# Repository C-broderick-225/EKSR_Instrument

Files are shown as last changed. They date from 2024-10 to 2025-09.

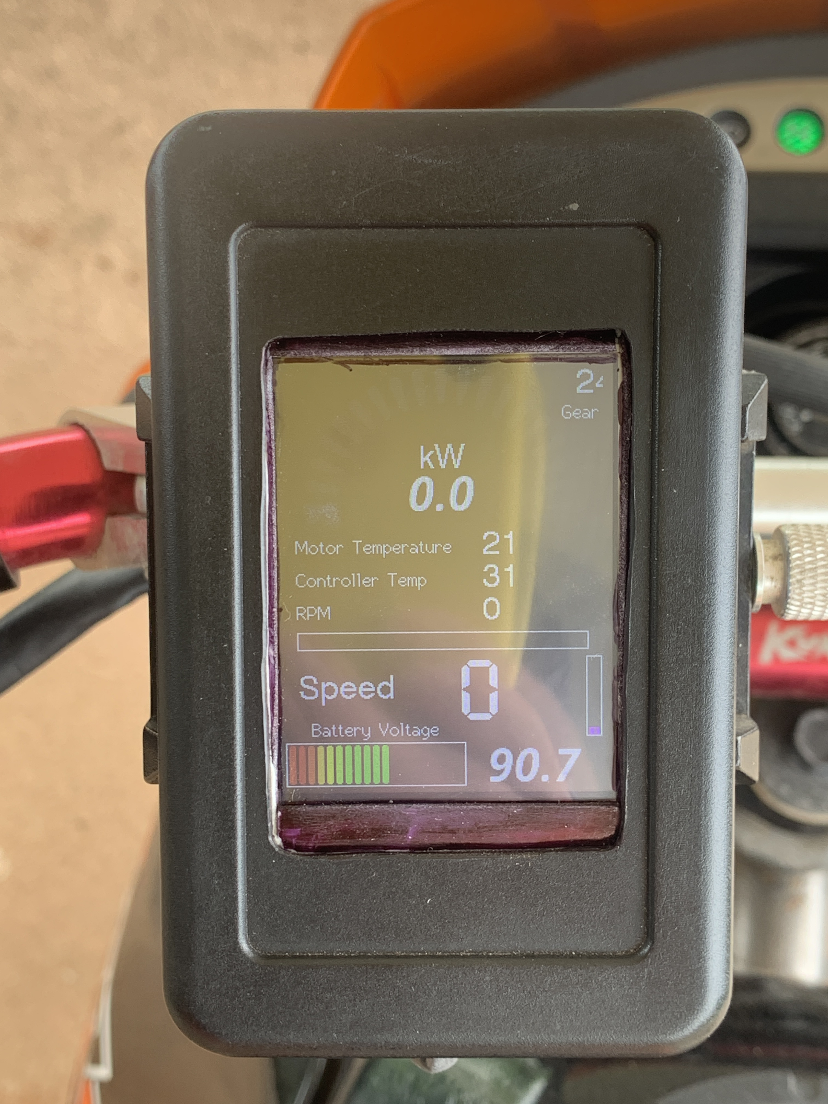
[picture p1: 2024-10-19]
media/EKSR_display.jpg

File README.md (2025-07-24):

# EKSR_Instrument (Fork)

**This repository is a fork of the original [EKSR_Instrument](https://github.com/magicmicros/EKSR_Instrument) project.**

## Overview
This project serves as the foundation for a new product based on the EKSR_Instrument hardware and firmware. It utilizes an ESP32-S3 microcontroller to receive and decode messages from FarDriver motor controllers over BLE, and displays the processed data on a 2.4" TFT touchscreen display.

## ESP32-S3 BLE Multi-Role Support
The ESP32-S3 (including the ESP32-S3-WROOM-1 module) is capable of acting as both a BLE client (central) and a BLE server (peripheral) simultaneously. This allows the device to connect to a BLE peripheral (such as a Far Driver controller) while also advertising its own BLE service for other clients (such as an Android phone) to connect and receive forwarded data. This multi-role (dual-role) capability is officially supported by Espressif and is useful for BLE proxy/bridge applications.

**Key facts:**
- The ESP32-S3 can operate as both a BLE client and server at the same time (multi-role topology).
- This is supported by the ESP-IDF and ESP-NimBLE host stack.
- Example use case: ESP32-S3 connects to a Far Driver controller as a client, and simultaneously acts as a server to forward data to a mobile app.

**Official documentation:**
- [ESP-IDF BLE Introduction: Bluetooth LE Network Topology](https://docs.espressif.com/projects/esp-idf/en/stable/esp32s3/api-guides/ble/get-started/ble-introduction.html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)
- [ESP-NimBLE API Reference](https://docs.espressif.com/projects/esp-idf/en/stable/esp32s3/api-reference/bluetooth/esp-nimble/index.html)

## Purpose
The goal of this fork is to extend and adapt the original EKSR_Instrument platform for new applications and features. All original design and implementation credit belongs to the original author. This repository will introduce new features, modifications, and documentation specific to the goals of the new product.

## FarDriver BLE Emulator
A FarDriver BLE emulator is included in the `emulator/` directory. This tool allows you to use an ESP32 (such as ESP-WROVER-E) as a BLE peripheral that mimics the FarDriver controller. It is useful for testing the EKSR Instrument firmware without requiring the actual controller hardware.

- The emulator advertises the same BLE service and characteristic UUIDs as the real controller.
- It sends realistic, cyclic data packets for rpm, voltage, temperature, throttle, and more.
- The EKSR Instrument client can connect and display the emulated data as if it were connected to a real FarDriver controller.

For build instructions, customization, and protocol details, see [`emulator/README.md`](emulator/README.md).

## License
See the LICENSE file for details.

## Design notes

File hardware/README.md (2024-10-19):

# Hardware for the EKSR Instrument.

The circuit is pretty straightforward.

The 12V input is dropped to 3.3V by an Alpha & Omega AOZ1284PI buck converter.

The ESP32-S3 controls the ILI9341 based TFT display though SPI and get touch data from the resistive touchcreen, using 4 ADC inputs.

The backlight is controlled with PWM through a N-channel FET.

Rev B adds a input voltage monitor though a 16:1 resistor divider, giving 900mV at 14.4V in.

Programming and log data output is, as usual for the ESP32's, through a 3.3V TTL level serial port.

Communication with the controller is though the built-in BLE in the ESP32-S3 (using Nimble BLE stack).

The board fits into a SZOMK AK-H-15 enclosure.\
This is not the enclosure used for the prototype, but it's the same inner dimensions and have an improved water seal.\
Still, the display have to be sealed against the enclosure, perhaps using a cutout "gasket" from 0.5mm rubber or silicone.

The `.brd` and `.sch` files in the `Fusion Files` folder, is EAGLE V9.x format.\
Project is originally made with Fusion 360/Fusion Electronics.

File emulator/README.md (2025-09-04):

# EKSR Instrument Emulator Suite

This directory contains a comprehensive suite of emulators and testing tools for the EKSR Instrument project. These tools allow you to test and develop the EKSR Instrument firmware without requiring the actual hardware components.

## Overview

The emulator suite includes:
- **FarDriver BLE Emulators** - Simulate the FarDriver controller's BLE communication
- **Hall Motor Emulator** - Simulate BLDC motor Hall sensor signals
- **Testing Tools** - Python scripts for validating emulator behavior and packet formats

## Components

### 1. FarDriver BLE Emulator

#### FarDriverEmulator (Enhanced)
- **Location**: `FarDriverEmulator/FarDriverEmulator.ino`
- **Features**: Enhanced FarDriver BLE protocol emulation with CRC-16/MODBUS checksums and dynamic ebike simulation
- **Use Case**: Accurate protocol emulation with proper error checking and realistic simulation

**Key Features**:
- CRC-16/MODBUS checksums for robust error detection
- Enhanced packet validation and error handling
- Improved timing and connection management
- Realistic ebike simulation with dynamic acceleration/deceleration patterns

### 2. Hall Motor Emulator

#### HallMotorEmulator
- **Location**: `MotorEmulator/HallMotorEmulator/HallMotorEmulator.ino`
- **Purpose**: Simulates BLDC motor Hall sensor signals for motor controller testing
- **Use Case**: Bench testing motor controllers without physical motors

**Features**:
- Generates standard 6-step commutation sequence
- Prevents "Hall Sensor Fault" errors during testing
- Configurable simulated motor speed
- Real-time debug output

### 3. Testing Tools

#### test_emulator_rpm.py
- **Purpose**: Validates RPM calculation logic between emulator and firmware
- **Tests**: Speed-to-RPM conversion accuracy and packet generation
- **Use Case**: Debugging speed display issues

#### test_packet_format.py
- **Purpose**: Validates packet format compliance with FarDriver protocol
- **Tests**: Packet structure, checksums, and data parsing
- **Use Case**: Ensuring emulator generates correct packet formats

#### test_speed_calculation.py
- **Purpose**: Tests speed calculation logic and identifies display issues
- **Tests**: Speed-to-RPM conversion and firmware parsing
- **Use Case**: Debugging speed calculation problems

## Quick Start Guide

### Setting Up FarDriver BLE Emulator

1. **Hardware Requirements**:
   - ESP32 development board (e.g., ESP-WROVER-E)
   - USB cable for programming and power

2. **Software Setup**:
   ```bash
   # Install Arduino IDE with ESP32 support
   # Install NimBLE-Arduino library
   ```

3. **Flashing**:
   - Open `FarDriverEmulator/FarDriverEmulator.ino` in Arduino IDE
   - Select your ESP32 board
   - Upload the sketch
   - Open Serial Monitor at 115200 baud

### Setting Up Hall Motor Emulator

1. **Hardware Requirements**:
   - ESP32 development board
   - Multimeter for pin identification
   - Jumper wires

2. **Wiring** (see MotorEmulator/README.md for detailed instructions):
   ```
   ESP32 Pin | Controller Hall Connector
   GND       | Ground
   GPIO 25   | Hall A Signal
   GPIO 26   | Hall B Signal
   GPIO 27   | Hall C Signal
   ```

3. **Flashing**:
   - Open `MotorEmulator/HallMotorEmulator/HallMotorEmulator.ino`
   - Upload to ESP32
   - Power on motor controller

### Running Tests

```bash
# Test RPM calculations
python test_emulator_rpm.py

# Test packet formats
python test_packet_format.py

# Test speed calculations
python test_speed_calculation.py
```

## FarDriver BLE Protocol Details

### Service Configuration
- **FarDriver Service**: UUID `FFE0`, Characteristic `FFEC`
- **Nordic UART Service**: Standard NUS implementation
- **Device Name**: `FarDriver_Emu`

### Packet Format
- **Size**: 16 bytes
- **Header**: `0xAA`
- **Indices**: 0, 1, 4, 13 (cycled every 30ms)
- **Checksum**: XOR (v1) or CRC-16/MODBUS (v2)

### Packet Types
- **Index 0**: Main data (RPM, gear, current iq/id)
- **Index 1**: Battery voltage
- **Index 4**: Controller temperature
- **Index 13**: Motor temperature and throttle position

### Ebike Simulation
The emulators provide realistic ebike simulation with:
- **30-second cycles**: Acceleration → Maintain → Deceleration
- **Dynamic data relationships**: All parameters calculated from speed
- **Realistic physics**: Proper gear ratios and wheel circumference
- **Visual feedback**: LED status indication

## Hall Motor Emulation Details

### 6-Step Commutation Sequence
```
Step | Hall A | Hall B | Hall C
-----|--------|--------|--------
1    | 1      | 0      | 1
2    | 0      | 0      | 1
3    | 0      | 1      | 1
4    | 0      | 1      | 0
5    | 1      | 1      | 0
6    | 1      | 0      | 0
```

### Configuration
- **Default Speed**: 500 RPM (20ms step delay)
- **Adjustable**: Modify `STEP_DELAY_MS` constant
- **RPM Calculation**: `RPM = 60,000 / (STEP_DELAY_MS × 6)`

## Testing and Validation

### Automated Testing
The Python test scripts validate:
- **Packet format compliance** with FarDriver protocol
- **RPM calculation accuracy** between emulator and firmware
- **Speed calculation logic** and display issues
- **Data relationships** and realistic simulation

### Manual Testing
1. **BLE Connection**: Verify device appears as "FarDriver_Emu"
2. **Data Reception**: Monitor Serial output for packet transmission
3. **Display Testing**: Connect to EKSR Instrument firmware
4. **Hall Signals**: Verify controller powers on without fault codes

## Troubleshooting

### Common Issues

#### BLE Connection Problems
- **Device not found**: Check ESP32 power and LED blinking
- **Connection drops**: Verify NimBLE library version
- **Data not received**: Check packet format and timing

#### Hall Emulator Issues
- **Controller still faults**: Verify wiring and pin identification
- **Unstable signals**: Check wire quality and ground connection
- **Wrong speed**: Adjust `STEP_DELAY_MS` value

#### Speed Display Issues
- **Speed shows 0**: Run `test_speed_calculation.py` to debug
- **Incorrect values**: Check RPM calculation and packet parsing
- **No updates**: Verify packet transmission frequency

### Debug Output
All emulators provide comprehensive Serial output:
- Connection events and client MAC addresses
- Packet data in hexadecimal format
- Simulation state and timing information
- Error conditions and status updates

## Development Guidelines

### Adding New Features
1. **Maintain protocol compatibility** with existing firmware
2. **Add comprehensive testing** for new functionality
3. **Update documentation** for any protocol changes
4. **Test with real hardware** when possible

### Protocol Extensions
- **New packet types**: Add to packet index enumeration
- **Additional services**: Follow BLE service guidelines
- **Enhanced simulation**: Maintain realistic data relationships

## Related Documentation

- **MotorEmulator/README.md**: Detailed Hall emulator documentation
- **Main project README**: EKSR Instrument overview
- **Firmware documentation**: EKSR Instrument firmware details
- **Hardware documentation**: PCB and assembly information

## Contributing

When contributing to the emulator suite:
1. **Test thoroughly** with both emulator versions
2. **Validate packet formats** using test scripts
3. **Update documentation** for any changes
4. **Maintain backward compatibility** when possible

---

For more information about the complete EKSR Instrument project, see the main project README.

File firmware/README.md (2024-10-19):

# Firmware

This is the firmware for the EKSR Instrument.

Code is for an ESP32-S3, and compiled with the Arduino IDE 2.3.3

It requires the TFT_eSPI library which is available in the Library Manager within the IDE
To setup the correct display driver and GPIOs used, you need to edit the **`User_Setup_Select.h`** file in the **`Arduino/libraries/TFT_eSPI`** folder.

Change the line that says:\
`  #include <User_Setup.h>                 // Default setup is root library folder`\
to:\
`  #include <User_Setups/Setup400_EKSR.h>  // Setup file for ESP32-S3 configured for ILI9341`

Then copy the Setup400_EKSR.h file to the **`Arduino/libraries/TFT_eSPI/User_Setups`** folder.

Also, you'll need the ESP32_ATouch library, which I have included here in the **`lib`** folder.
Simply move the **`ESP32_ATouch`** folder to your **`Arduino/libraries`** folder.

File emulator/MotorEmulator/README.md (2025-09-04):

# ESP32 Hall Sensor Emulator for BLDC Motor Controllers

This project provides a simple yet effective way to emulate the Hall sensor signals of a Brushless DC (BLDC) motor using an ESP32 development board. It is designed for developers and hobbyists who need to bench test motor controllers (such as Sabvoton, FarDriver, Kelly, etc.) without a physical motor attached.

## Primary Goal

The primary goal is to prevent the common "Hall Sensor Fault" error (often indicated by a single repeating beep) that controllers report when they are powered on without receiving valid Hall signals.

## Features

- **Generates the standard 6-step commutation sequence** for BLDC motors
- **Simulates a slowly spinning motor** to satisfy the controller's self-test
- **Prevents common Hall sensor fault codes** during bench testing
- **Configurable simulated motor speed** via a single delay parameter
- **Outputs the current emulation state** to the Serial Monitor for easy debugging

## Why You Need This

This tool is essential for several common development tasks:

### Bench Testing
Power on and test a controller's basic functions (like BLE connectivity or parameter saving) without the noise and bulk of a physical motor.

### Protocol Reverse Engineering
To sniff and decode the data protocol (e.g., UART or CAN bus), the controller must be in a "healthy," non-faulted state. This emulator tricks the controller into this state, allowing you to capture normal operating data packets.

### Peripheral Firmware Development
If you are building a custom display or Human Interface Module (HIM), this provides a stable and predictable signal source without needing a full e-bike setup on your desk.

## Hardware Requirements

- **ESP32 Development Board** (any common model will work)
- **Multimeter** (essential for safely identifying controller pins)
- **Jumper wires** for making connections
- **Micro-USB cable** to power and program the ESP32

## Wiring and Connections

**WARNING: Incorrect wiring can permanently damage your motor controller or your ESP32. Proceed with caution and always verify pinouts with a multimeter.**

### Step 1: Identify Controller Pins

Before connecting anything, you must identify the pins on your controller's Hall sensor connector.

1. **Power on the motor controller**
2. **Using your multimeter set to DC Volts**, carefully probe the pins in the Hall connector
3. **Find the Ground (GND) pin**
4. **Find the +5V Power pin** (it should read approximately 5V relative to GND)
5. **The remaining three pins are the Hall signals** (Hall A, Hall B, Hall C)

### Step 2: Connect the ESP32

**Important: The ESP32 should be powered by its own USB cable, not by the controller.**

| ESP32 Pin | Controller Hall Connector | Typical Wire Color |
|---|---|---|
| GND | Ground | Black |
| GPIO 25 | Hall A Signal | Yellow / Green / Blue |
| GPIO 26 | Hall B Signal | Yellow / Green / Blue |
| GPIO 27 | Hall C Signal | Yellow / Green / Blue |

**DO NOT CONNECT ANYTHING TO THE CONTROLLER'S +5V HALL POWER PIN** (typically Red). The ESP32 is self-powered, and the controller has its own internal pull-up resistors for the signal lines.

## Software Setup

1. **Install the Arduino IDE**
2. **Add ESP32 board support** to the Arduino IDE. Follow [this guide from Espressif](https://docs.espressif.com/projects/arduino-esp32/en/latest/installing.html)
3. **Open the `HallMotorEmulator.ino` file** in the Arduino IDE
4. **Select your ESP32 board** from the Tools > Board menu
5. **Select the correct COM port** from the Tools > Port menu
6. **Click the "Upload" button**

## Usage Procedure

1. **Flash the emulator sketch** to your ESP32. You can open the Serial Monitor (baud rate 115200) to see the debug output confirming it is running
2. **Power down the motor controller**
3. **Make the physical connections** as described in the wiring section
4. **Power on the ESP32** via its USB cable
5. **Power on the motor controller**
6. **Listen**: The controller should now power on without the repeating beep of a Hall fault
7. **You can now proceed** with your primary task, such as sniffing the data lines for reverse engineering

## Configuration

The simulated speed of the motor can be adjusted by changing a single constant in the code:

```cpp
// Define the delay between steps. This controls the simulated RPM.
// 20ms is a good starting point, simulating a slow, healthy spin.
#define STEP_DELAY_MS 20
```

- **Smaller value** (e.g., 10) simulates a faster motor
- **Larger value** (e.g., 50) simulates a slower motor
- **For most testing purposes**, the default value of 20 is sufficient

## How It Works

The emulator works by cycling through the standard 6-step commutation sequence required by BLDC motors. The ESP32 sets its GPIO pins to HIGH (3.3V) or LOW (0V) in a specific pattern. The motor controller's Hall sensor inputs have internal pull-up resistors connected to their 5V line. The ESP32's GPIOs are strong enough to pull these signal lines down to ground (LOW), creating a valid signal that the controller can read.

### 6-Step Commutation Sequence

The emulator cycles through these 6 states continuously:

| Step | Hall A | Hall B | Hall C |
|---|---|---|---|
| 1 | 1 | 0 | 1 |
| 2 | 0 | 0 | 1 |
| 3 | 0 | 1 | 1 |
| 4 | 0 | 1 | 0 |
| 5 | 1 | 1 | 0 |
| 6 | 1 | 0 | 0 |

### RPM Calculation

The approximate simulated RPM can be calculated as:
```
RPM = 60,000 / (STEP_DELAY_MS × 6)
```

For example, with `STEP_DELAY_MS = 20`:
```
RPM = 60,000 / (20 × 6) = 60,000 / 120 = 500 RPM
```

## Debug Output

The emulator provides real-time feedback via the Serial Monitor:

```
=== ESP32 Hall Sensor Emulator for BLDC Motor Controllers ===
Starting ESP32 Hall Sensor Emulator...
Step delay: 20 ms (simulated RPM: ~500)
Emulator running. Connect to controller and power cycle it.
Expected behavior: Controller should power on without Hall fault beeps.
Debug output will show current Hall sensor states.
---
Step 1: Hall A=1, Hall B=0, Hall C=1 (Cycle 1)
Step 2: Hall A=0, Hall B=0, Hall C=1 (Cycle 1)
Step 3: Hall A=0, Hall B=1, Hall C=1 (Cycle 1)
...
```

## Troubleshooting

### Controller Still Shows Hall Fault
- **Check wiring**: Ensure all three Hall signal pins are connected
- **Verify pin identification**: Use a multimeter to confirm you've identified the correct pins
- **Check ESP32 power**: Ensure the ESP32 is powered via USB, not from the controller
- **Try different speed**: Increase `STEP_DELAY_MS` to 30 or 50 for slower simulation

### ESP32 Not Responding
- **Check USB connection**: Ensure the ESP32 is properly connected and recognized
- **Verify board selection**: Make sure you've selected the correct ESP32 board in Arduino IDE
- **Check COM port**: Ensure the correct serial port is selected

### Unstable Signals
- **Check wire quality**: Use good quality jumper wires with proper connections
- **Verify ground connection**: Ensure the ESP32 GND is connected to the controller GND
- **Check for interference**: Keep wires away from power cables and motors

## Safety Notes

- **Never connect the ESP32 to the controller's +5V power pin**
- **Always power down both devices before making connections**
- **Use a multimeter to verify pin identification before connecting**
- **Start with conservative timing values** (20-30ms) to avoid stressing the controller
- **Monitor the controller for any unusual behavior** during testing

## Related Projects

This emulator is part of the larger EKSR Instrument project, which includes:
- **FarDriver BLE Emulator**: For testing BLE communication protocols
- **EKSR Instrument Firmware**: The main instrument firmware for ESP32-S3
- **PC Display Software**: For monitoring and data visualization

For more information about the complete project, see the main project README.

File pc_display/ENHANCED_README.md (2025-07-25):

# EKSR Instrument PC Display - Enhanced Version

## Overview

This enhanced version of the EKSR Instrument PC Display provides a modern, polished interface with improved visual design, animations, and user experience.

## Key Enhancements

### 🎨 **Modern UI Design**
- **Dark Theme**: Professional dark color scheme with carefully chosen colors
- **Typography**: Modern fonts (Segoe UI) with proper hierarchy
- **Layout**: Grid-based layout with proper spacing and alignment
- **Sidebar**: Dedicated control panel with terminal and connection status

### 📊 **Interactive Gauges**
- **Animated Gauges**: Smooth circular gauges for RPM, throttle, and power
- **Real-time Updates**: 20 FPS smooth animations
- **Color Coding**: Dynamic colors based on values (green/yellow/red)
- **Visual Feedback**: Immediate response to data changes

### 🎯 **Improved Data Visualization**
- **Large Displays**: Prominent speed and voltage displays
- **Battery Indicator**: Visual battery level bar with color coding
- **Temperature Monitoring**: Clear temperature displays for motor and controller
- **Gear Display**: Prominent gear indicator

### 🔧 **Enhanced Controls**
- **Modern Buttons**: Hover effects and consistent styling
- **Connection Status**: Real-time connection indicator with status text
- **Terminal Controls**: Pause/resume and clear functionality
- **Status Bar**: Time display and application information

### 📱 **Responsive Design**
- **Resizable Window**: Minimum size constraints for usability
- **Grid Layout**: Flexible layout that adapts to window size
- **Proper Spacing**: Consistent padding and margins throughout

### 🎨 **Visual Polish**
- **Gradient Effects**: Subtle background gradients
- **Smooth Animations**: 60 FPS gauge animations
- **Color Consistency**: Unified color scheme across all elements
- **Professional Appearance**: Clean, modern interface design

## Features

### Connection Management
- Automatic BLE device scanning
- Real-time connection status
- Manual connect/disconnect controls
- Connection retry logic

### Data Display
- **Power Gauge**: Circular gauge showing power output (0-5000W)
- **Speed Display**: Large digital speedometer (km/h)
- **Voltage Monitor**: Battery voltage with visual indicator
- **RPM Gauge**: Engine RPM with color-coded levels
- **Throttle Gauge**: Throttle position indicator
- **Temperature Monitoring**: Motor and controller temperatures
- **Gear Display**: Current gear position

### Terminal Features
- **Real-time Logging**: Live data packet logging
- **Color-coded Messages**: Different colors for different message types
- **Pause/Resume**: Control terminal output
- **Auto-scroll**: Automatic scrolling to latest messages
- **Message Filtering**: Limit message history to prevent memory issues
- **Search Functionality**: Search through terminal content with highlighting
- **Packet Inspector**: Detailed packet analysis and statistics

### Data Recording
- **Auto-Save CSV**: Data is automatically saved to CSV files during recording
- **Organized Storage**: All data files saved in dedicated `data/` directory
- **Timestamped Files**: Automatic filename generation with timestamps
- **Data Folder Access**: Quick access to data directory via folder button
- **Settings Control**: Auto-save option available in settings
- **Multiple Formats**: Support for CSV and JSON export formats

## Installation

1. Install Python dependencies:
```bash
pip install -r requirements_enhanced.txt
```

2. Run the enhanced application:
```bash
python pc_display_enhanced.py
```

## Usage

1. **Start the Application**: Launch the enhanced PC display
2. **Connect to Device**: The app will automatically scan for FarDriver devices
3. **Monitor Data**: View real-time data through the various gauges and displays
4. **Terminal Logging**: Monitor raw data packets in the terminal panel
5. **Control Display**: Use pause/resume and clear controls as needed
6. **Record Data**: Click "Start Recording" to begin auto-saving data to CSV files
7. **Access Data**: Click the folder button (📁) to open the data directory

## Data Directory Structure

The application automatically creates and manages a `data/` directory for all recorded files:

```
pc_display/
├── data/                          # Data storage directory
│   ├── eksr_data_20250725_143307.csv
│   ├── eksr_data_20250725_143353.csv
│   └── eksr_data_20250725_143400.json
├── pc_display_enhanced.py         # Main application
├── requirements_enhanced.txt      # Dependencies
└── README.md                      # Documentation
```

### Data File Format

CSV files contain the following columns:
- **Timestamp**: ISO format timestamp
- **Throttle**: Throttle position (0-4095)
- **Gear**: Current gear (1-3)
- **RPM**: Engine RPM
- **Controller_Temp_C**: Controller temperature in Celsius
- **Motor_Temp_C**: Motor temperature in Celsius
- **Speed_kmh**: Calculated speed in km/h
- **Power_W**: Power output in watts
- **Voltage_V**: Battery voltage
- **Packet_Count**: Total packets received
- **Latency_ms**: Average packet latency

## Technical Improvements

### Performance
- **Optimized Updates**: 20 FPS display updates for smooth animations
- **Memory Management**: Limited terminal history to prevent memory issues
- **Efficient Rendering**: Optimized canvas drawing for gauges

### Code Quality
- **Modular Design**: Separate classes for different UI components
- **Consistent Styling**: Centralized color and font definitions
- **Error Handling**: Improved error handling and user feedback
- **Documentation**: Comprehensive code comments and documentation

### User Experience
- **Intuitive Layout**: Logical arrangement of controls and displays
- **Visual Feedback**: Immediate response to user actions
- **Professional Appearance**: Clean, modern interface design
- **Accessibility**: Clear labels and consistent styling

## Comparison with Original

| Feature | Original | Enhanced |
|---|---|---|
| Layout | Basic frame layout | Grid-based responsive layout |
| Colors | Basic black/white | Professional dark theme |
| Gauges | Simple bars | Animated circular gauges |
| Typography | Arial fonts | Modern Segoe UI fonts |
| Animations | None | Smooth 20 FPS animations |
| Controls | Basic buttons | Modern buttons with hover effects |
| Terminal | Basic text widget | Enhanced with color coding |
| Status | Simple labels | Interactive status indicators |

## Future Enhancements

Potential improvements for future versions:
- **Data Logging**: Save data to files for analysis
- **Graphs**: Real-time plotting of data trends
- **Alerts**: Configurable alerts for temperature/power limits
- **Themes**: Multiple color themes
- **Fullscreen Mode**: Dedicated fullscreen display mode
- **Data Export**: Export data in various formats
- **Configuration**: User-configurable display options

## Requirements

- Python 3.7+
- bleak library for BLE communication
- tkinter (usually included with Python)
- FarDriver BLE emulator or compatible device

## Troubleshooting

### Connection Issues
- Ensure FarDriver emulator is running
- Check Bluetooth is enabled
- Verify device is discoverable

### Display Issues
- Ensure minimum window size (1000x700)
- Check Python and tkinter installation
- Verify all dependencies are installed

### Performance Issues
- Close other applications to free system resources
- Reduce terminal logging if experiencing lag
- Check system Bluetooth performance

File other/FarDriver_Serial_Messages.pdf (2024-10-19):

Fardriver serial communications messages. (speed is 19200 bps, 8 bit, no stop bits) | Jesper, 2024-10-17
Sync | Address | Addr (Hex) | Byte 0 | Byte 1 | Byte 2 | Byte 3 | Byte 4 | Byte 5 | Byte 6 | Byte 7 | Byte 8 | Byte 9 | Byte 10 | Byte 11
0xAA | 0 | 00 | MTPAAngle | HALL position | Gear/Roll | Follow | RPM | | Motor Error Flags | Bit 7 = Brake | Iqout | | Idout
0xAA | 1 | 01 | Voltage (100mV steps) | | Current | | ModRatio? Some Thr data? 0-70 hex | Workstat | Iqin | | Idin | | Throttle
0xAA | 2 | 02
0xAA | 3 | 03 | Zero Phase A | | Zero Phase C
0xAA | 4 | 04 | Bit 0-1 = Thr Mode, Bit 2-3 = WeakChar | | MOS temp (deg C) | | | | Line Current Coefficient | | Temp Coeff
0xAA | 5 | 05 | Never seen any messages with this address
0xAA | 6 | 06 | Motor Limit Coeff 500 rpm | Motor Limit Coeff 1000 rpm | Motor Limit Coeff 1500 rpm | Motor Limit Coeff 2000 rpm | Motor Limit Coeff 2500 rpm | Motor Limit Coeff 3000 rpm | Motor Limit Coeff 3500 rpm | Motor Limit Coeff 4000 rpm | Motor Limit Coeff 4500 rpm | Motor Limit Coeff 5000 rpm | Motor Limit Coeff 5500 rpm | Motor Limit Coeff 6000 rpm
0xAA | 7 | 07 | Motor Limit Coeff 6500 rpm | Motor Limit Coeff 7000 rpm | Motor Limit Coeff 7500 rpm | Motor Limit Coeff 8000 rpm | Motor Limit Coeff 8500 rpm | Motor Limit Coeff 9000 rpm | | CAN Bus # | Speedo Analog RPM | | PID AN | PID LM
0xAA | 8 | 08 | | | | | | | | | | Bit 0 - MotorDir
0xAA | 9 | 09 | | | | | Max Speed (rpm) | | Mid Speed Max (rpm) | | | ACCStep | Bit 6= ! MOE, MonitorWay in bits 0-2 and 7 | Bit 1-3 = WeakResp, Bit 5-7 = Backthrottle
0xAA | 10 | 0A | 4 times Max Line Current | | | | | Rated Power (100W steps) | 4 times Max Phase Current | | Changes with RatedVoltage | PID SpeedSKl | Throttle LOW (50mV steps) | Throttle HIGH (50mV steps)
0xAA | 11 | 0B | OV Protect | | OV Restore | | LowVolProt (100mV steps) | | LowVolRestore (100mV steps) | | 4 times StopBack Current | | 4 times MaxBack Current
0xAA | 12 | 0C | | | ECOAccRatio low 4 bits | PID StartKl | PID MidKl | PID MaxKl | PID StartKP | PID MidKP | PID MaxKP | | Time???
0xAA | 13 | 0D | motor temp (deg C) | | Throttle ADC Reading, 12 bits | | | Battery Capacity (Ah) | Bit 0-2 = Brake Config | Bit 0-2 = PC13 config | | | Back Speed
0xAA | 14 | 0E | | | Temp Detect/Sensortype | | | | | | | Bit 0-2 = Park, Bit 3 =?, Bit 4-7 = SpeedPulse | Low Speed Max (rpm)
0xAA | 15 | 0F | | | | Bit 0=OverTempMot | | Bit 1 - MotorDir | something with default gear setting | bit 2 = reverse | | | | something with gear setting
0xAA | 16 | 10
0xAA | 17 | 11 | something related to reverse/gear and the setting of MaxPhase Current
0xAA | 18 | 12 | | | | | | LowSpeedLineRatio (0x80 == 100%) | MidSpeedLineRatio (0x80 == 100%) | LowSpeedPhaseRatio (0x80 == 100%) | MidSpeedPhaseRatio (0x80 == 100%)
0xAA | 19 | 13
0xAA | 20 | 14
0xAA | 21 | 15 | | | | | | | Bit 0-5 = Morsecode
0xAA | 22 | 16 | EREG 500 RPM in % | EREG 1000 RPM in % | EREG 1500 RPM in % | EREG 2000 RPM in % | EREG 2500 RPM in % | EREG 3000 RPM in % | EREG 3500 RPM in % | EREG 4000 RPM in % | EREG 4500 RPM in % | EREG 5000 RPM in % | EREG 5500 RPM in % | EREG 6000 RPM in %
0xAA | 23 | 17 | EREG 6500 RPM in % | EREG 7000 RPM in % | EREG 7500 RPM in % | EREG 8000 RPM in % | EREG 8500 RPM in % | EREG 9000 RPM in % | | | | | FreeThrottle

Verified field by debugging my controller
Field with verified bits, but there may be more
Field where functionality is not understood
Field titles from other sources, thas has not been verified Unknown field
Field 0.2 | Field 0.3 | Field 0.6 - 0.7 | Field 0.8 - 0.11 | Field 1.2 | Field 0.8 - 0.11
Bit 6 = regen?????? | follow enabled | 24
| | According to other docs, this should be a 16 bit field with motor error codes. However, these doesn't match the Brake bit 7 in 0.7 | Definitely some currents here. The field names are from another source | I never get anything else than zero here. | Not sure what this is.
Bit 5 = Direction Forward | follow dis | 25
Bit 4 = Rolling | EABS when brake | 26
Bit 2-3 = Gear, 00=high, 11=mid, 10=low, (00=Disabled) | EABS when release | 27
Bit 0-1 = Gear, 10=Reverse, 01=Forward, 00=Neutral
Field 1.0, 1.6, 11.8 and 11.10 | Field 5.5 - 5.8 | 17.0 - 17.1 | 10.8
The actual current is 1/4 of the value in the field | Max value here is 0x80, which corresponds to 100%. | | Related to the setting of Rated Voltage.
Max Phase Current | Field value | Rated Voltage | Field value
20 | 195 | 40 | 100
30 | 292 | 50 | 100
40 | 390 | 55 | 80
50 | 488 | 60 | 57
60 | 585 | 65 | 15
70 | 683 | 70 | 0
80 | 781
90 | 878
100 | 976

NOTE: This is decoded with a ND96530_23_ARG15, that was reflashed with ND72530_23_ARA17, as original firmware was lost.

## This might affect some of the values

This field is related to the setting of Max Phase Current. But also, on the setting of the default Gear Setting.

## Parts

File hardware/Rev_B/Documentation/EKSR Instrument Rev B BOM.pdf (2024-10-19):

# Bill Of Materials, EKSR Instrument, Rev B

Qty | Part | Value | Package | Description | Manufacturer | Manufacturer Partno | Distributor | Distributor Partno | Comments | Cost, single qty
4 | C1,C7,C10,C13 | 10u | C0603 | CAPACITOR, European symbol | Murata Electronics | GRM188R61E106KA73J | Digikey | 490-GRM188R61E106KA73JCT-ND | | 1.08
2 | C2,C8 | 100n | C0603 | Capacitor Ceramic, X7R, 0603 | TDK Corporation | C1608X7R1E104K080AA | Digikey | 445-1316-1-ND | | 0.2
5 | C3,C4,C5,C6,C11 | 10n | C0603 | Capacitor Ceramic, X7R, 0603 | Kemet | C0603C103K5RACTU | Digikey | 399-1091-1-ND | | 0.5
1 | C9 | 1n5 | C0603 | Capacitor Ceramic, X7R, 0603 | Samsung Electro | CL10B152KB8WPNC | Digikey | 1276-6666-1-ND | | 0.1
1 | C12 | 100u/10 | CT3528 | Capacitor Tantalum, 3528 | AVX Corporation | F931A107KBA | Digikey | 478-8195-1-ND | | 0.86
2 | D1,D2 | SL54AFL | DO221-AC | Shottky Diode, 40V, 5A, SMA_FL | Micro Commercial | SL54AFL-TP | Digikey | SL54AFL-TPMSCT-ND | | 1
1 | DISP1 | TFT_2.4_A | TFT_2.4_A | 2.4" TFT LCD with Touch, ILI9341 Controller | | | HongKong CCD Limited | | https://vi.aliexpress.com/item/3256806944734005.html | 3.5
1 | IC1 | AOZ1284PI | SO8_EDP | EZBuckTM 4A Simple Adjustable Buck Regulator | Alpha & Omega Semconductor | AOZ1284PI | Digikey | 785-1689-1-ND | | 1.38
1 | J1 | DEBUG/PROG | MA03-1W | 3x1 pos 0.1" pin header, RA | AdamTech | PH1RB-03-UA | Digikey | 2057-PH1RB-03-UA-ND | | 0.12
1 | L1 | 10uH | SPM6530 | Inductor, 10uH, 4.2A, 86mR | TDK Corporation | SPM6530T-100M-HZ | Digikey | 445-180110-1-ND | | 3.9
1 | M1 | ESP32-S3-WROOM | ESP32-S3-WROOM | ESP32-S3 WROOM module. | Espressif | ESP32-S3-WROOM-1-N16R8 | Digikey | 1965-ESP32-S3-WROOM-1-N16R8CT-ND | | 0.37
1 | Q1 | DMN3023L-7 | SOT-23 | MOSFET N-CH 30V 6.2A SOT23 | Diodes Inc | DMN3023L-7 | Digikey | DMN3023L-7DICT-ND | | 0.4
1 | R1 | 1k | R0603 | Resistor, 1%, 0603 | Stackpole Electronics | RMCF0603FT1K00 | Digikey | RMCF0603FT1K00CT-ND | | 0.1
4 | R2,R3,R6,R8 | 10k | R0603 | Resistor, 1%, 0603 | Stackpole Electronics | RMCF0603FT10K0 | Digikey | RMCF0603FT10K0CT-ND | | 0.1
1 | R4 | 100k | R0603 | Resistor, 1%, 0603 | Stackpole Electronics | RMCF0603FT100K | Digikey | RMCF0603FT100KCT-ND | | 0.1
1 | R5 | 31k6 | R0603 | Resistor, 1%, 0603 | Stackpole Electronics | RMCF0603FT31K6 | Digikey | RMCF0603FT31K6CT-ND | | 0.1
1 | R7 | 47k | R0603 | Resistor, 1%, 0603 | Stackpole Electronics | RMCF0603FT47K0 | Digikey | RMCF0603FT47K0CT-ND | | 0.1
1 | R9 | 180k | R0603 | Resistor, 1%, 0603 | Stackpole Electronics | RMCF0603FT180K | Digikey | RMCF0603FT180KCT-ND | | 0.1
1 | R10 | 11k8 | R0603 | Resistor, 1%, 0603 | Stackpole Electronics | RMCF0603FT11K8 | Digikey | RMCF0603FT11K8CT-ND | | 0.1
1 | R11 | 787R | R0603 | Resistor, 1%, 0603 | Stackpole Electronics | RMCF0603FT787R | Digikey | RMCF0603FT787RCT-ND | | 0.1
2 | SW1,SW2 | BOOT, RESET | PTS820 | Microminiature SMT Top Actuated Pushbutton | C&K | PTS820 J20M SMTR LFS | Digikey | CKN10505CT-ND | | 1.98
1 | AK-H-15 | Enclosure | SZOMK | AK-H-15 | SZOMK Enclosure 03 Store | AK-H-15 | https://vi.aliexpress.com/item/2251832638947727.html | 5.26
Total (USD) | 21.45

2024-10-19

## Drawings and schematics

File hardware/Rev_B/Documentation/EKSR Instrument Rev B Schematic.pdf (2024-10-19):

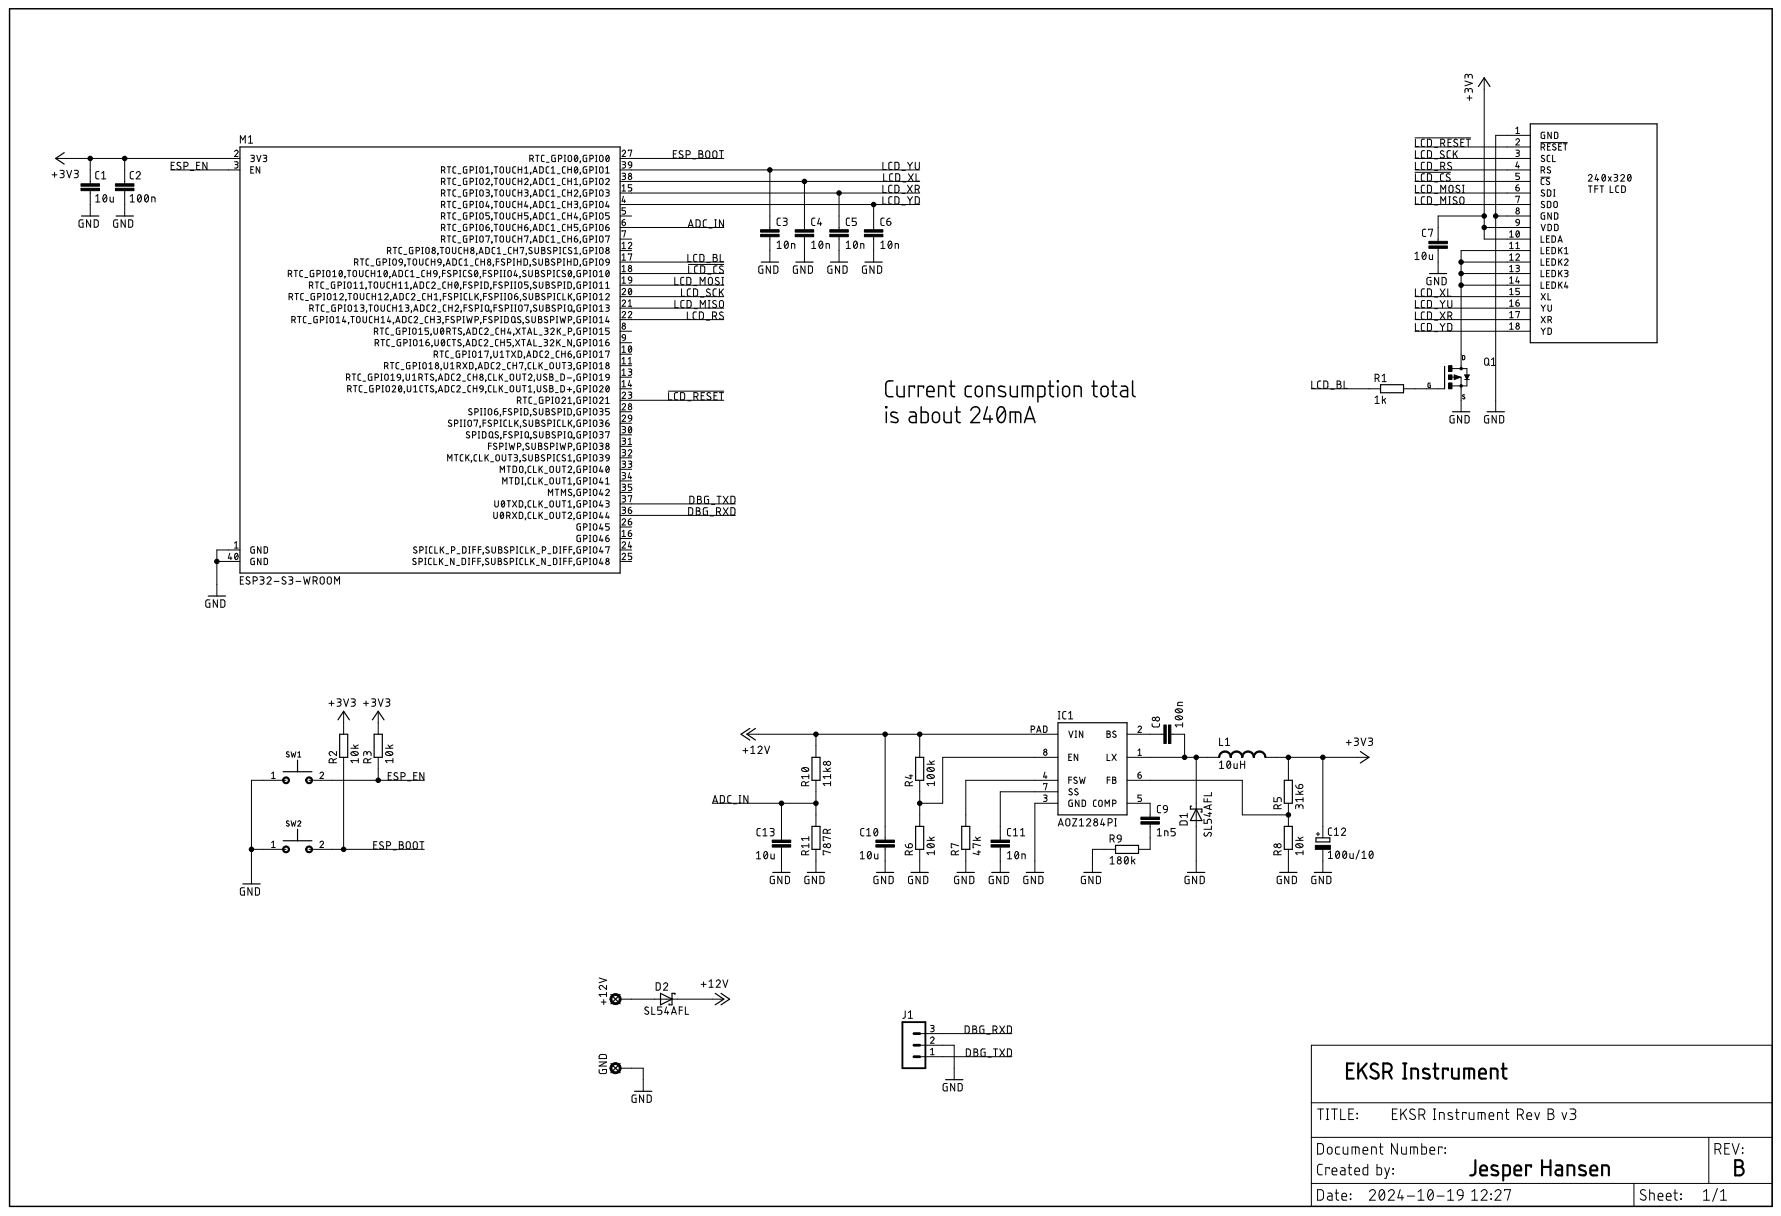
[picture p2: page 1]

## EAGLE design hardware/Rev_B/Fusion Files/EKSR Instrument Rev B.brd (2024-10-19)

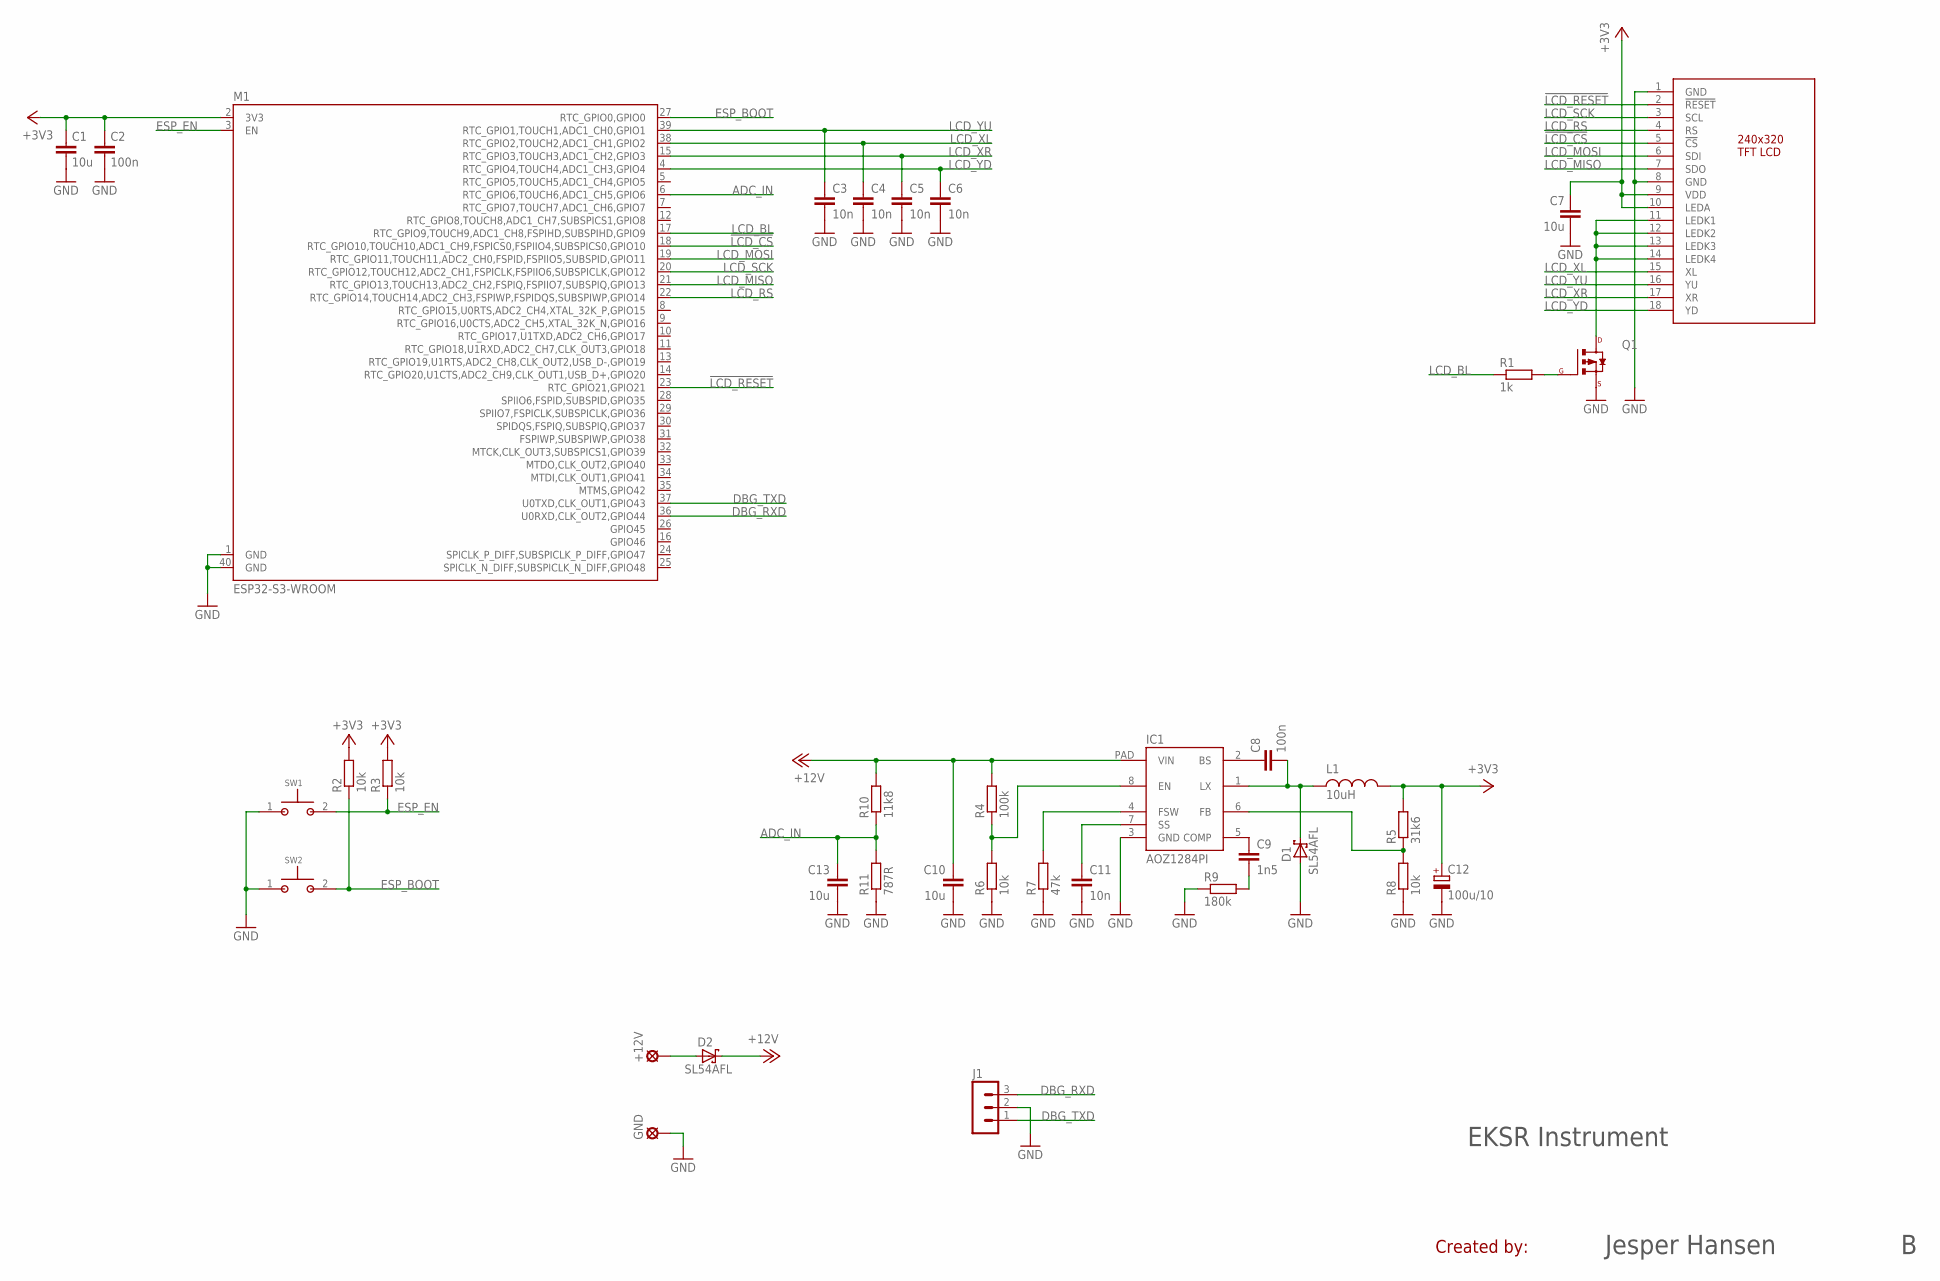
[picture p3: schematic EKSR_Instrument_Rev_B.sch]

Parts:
+12V: LSP13
C1, C7, C10, C13: 10u; C0603
C2, C8: 100n; C0603
C3, C4, C5, C6, C11: 10n; C0603
C9: 1n5; C0603
C12: 100u/10; CT3528
D1, D2: SL54AFL; DO221-AC
DISP1: TFT_2.4_A"; TFT_2.4_A2
GND: LSP13
IC1: AOZ1284PI; SO8_EDP
J1: MA03-1W
L1: 10uH; SPM6530
M1: ESP32-S3-WROOM
Q1: MOSFET_P; SOT-23
R1: 1k; R0603
R2, R3, R6, R8: 10k; R0603
R4: 100k; R0603
R5: 31k6; R0603
R7: 47k; R0603
R9: 180k; R0603
R10: 11k8; R0603
R11: 787R; R0603
SW1, SW2: PTS820

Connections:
!LCD_CS: DISP1.5 (!CS), M1.18 (RTC_GPIO10,TOUCH10,ADC1_CH9,FSPICS0,FSP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)
!LCD_RESET: DISP1.2 (!RESET), M1.23 (RTC_GPIO21,GPIO21)
+3V3: C1.1, C2.1, C7.1, C12.+, DISP1.9 (VDD), DISP1.10 (LEDA), L1.2, M1.2 (3V3), R2.2, R3.2, R5.2
+12V: C10.1, D2.C, IC1.PAD (VIN), R4.2, R10.2
ADC_IN: C13.1, M1.6 (RTC_GPIO6,TOUCH6,ADC1_CH5,GPIO6), R10.1, R11.2
DBG_RXD: J1.3, M1.36 (U0RXD,CLK_OUT2,GPIO44)
DBG_TXD: J1.1, M1.37 (U0TXD,CLK_OUT1,GPIO43)
ESP_BOOT: M1.27 (RTC_GPIO0,GPIO0), R2.1, SW2.2
ESP_EN: M1.3 (EN), R3.1, SW1.2
GND: C1.2, C2.2, C3.2, C4.2, C5.2, C6.2, C7.2, C10.2, C11.2, C12.-, C13.2, D1.A, DISP1.1 (GND), DISP1.8 (GND), GND.MP, IC1.3 (GND), J1.2, M1.1 (GND), M1.40 (GND), Q1.2 (P_S), R6.1, R7.1, R8.1, R9.1, R11.1, SW1.1, SW2.1
LCD_BL: M1.17 (RTC_GPIO9,TOUCH9,ADC1_CH8,FSPIHD,SUBSPI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), R1.1
LCD_MISO: DISP1.7 (SDO), M1.21 (RTC_GPIO13,TOUCH13,ADC2_CH2,FSPIQ,FSPII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)
LCD_MOSI: DISP1.6 (SDI), M1.19 (RTC_GPIO11,TOUCH11,ADC2_CH0,FSPID,FSPII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)
LCD_RS: DISP1.4 (RS), M1.22 (RTC_GPIO14,TOUCH14,ADC2_CH3,FSPIWP,FSPI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)
LCD_SCK: DISP1.3 (SCL), M1.20 (RTC_GPIO12,TOUCH12,ADC2_CH1,FSPICLK,FSP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)
LCD_XL: C4.1, DISP1.15 (XL), M1.38 (RTC_GPIO2,TOUCH2,ADC1_CH1,GPIO2)
LCD_XR: C5.1, DISP1.17 (XR), M1.15 (RTC_GPIO3,TOUCH3,ADC1_CH2,GPIO3)
LCD_YD: C6.1, DISP1.18 (YD), M1.4 (RTC_GPIO4,TOUCH4,ADC1_CH3,GPIO4)
LCD_YU: C3.1, DISP1.16 (YU), M1.39 (RTC_GPIO1,TOUCH1,ADC1_CH0,GPIO1)
unnamed: IC1.6 (FB), R5.1, R8.2
unnamed: Q1.1 (P_G), R1.2
unnamed: DISP1.11 (LEDK1), DISP1.12 (LEDK2), DISP1.13 (LEDK3), DISP1.14 (LEDK4), Q1.3 (P_D)
unnamed: +12V.MP, D2.A
unnamed: IC1.8 (EN), R4.1, R6.2
unnamed: C8.1, IC1.2 (BS)
unnamed: IC1.4 (FSW), R7.2
unnamed: C11.1, IC1.7 (SS)
unnamed: C9.2, R9.2
unnamed: C9.1, IC1.5 (COMP)
SW: C8.2, D1.C, IC1.1 (LX), L1.1

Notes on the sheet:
EKSR Instrument
Created by:
Jesper Hansen

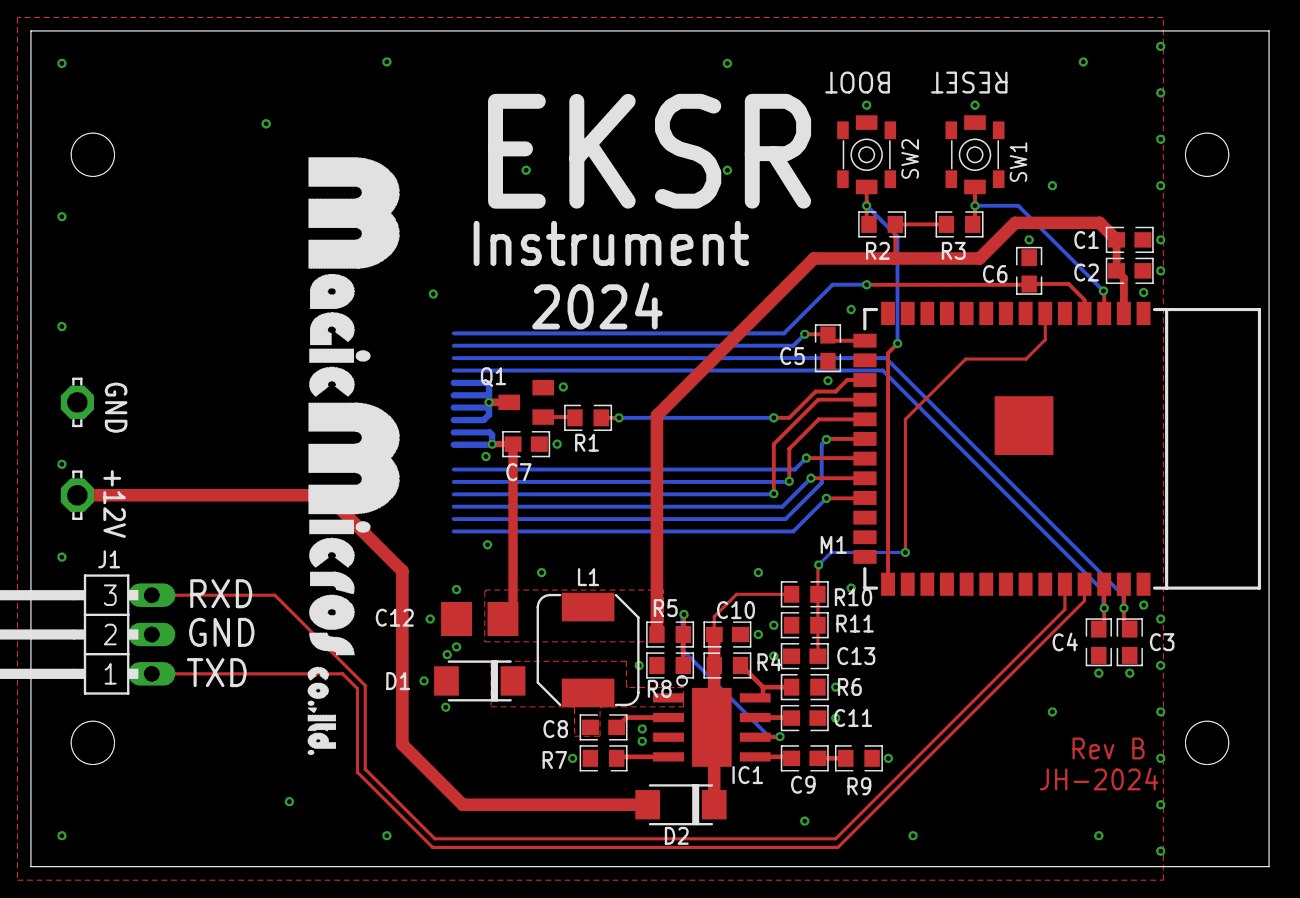
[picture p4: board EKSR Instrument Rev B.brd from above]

Board: 2 copper layers, 80.0 x 54.0 mm, 36 parts (1 on the bottom side), 30 nets.

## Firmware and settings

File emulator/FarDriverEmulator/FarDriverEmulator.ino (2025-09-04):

/*
 * FarDriver BLE Emulator for EKSR Instrument
 * 
 * This emulator implements the FarDriver controller communication protocol
 * used by the EKSR Instrument firmware. The protocol uses 16-byte packets
 * with the following structure:
 * 
 * Packet Format:
 * - Byte 0: Header (0xAA)
 * - Byte 1: Packet Index (0, 1, 4, 13)
 * - Bytes 2-13: Data (12 bytes)
 * - Bytes 14-15: CRC-16/MODBUS Checksum (2 bytes, little-endian)
 * 
 * Packet Types:
 * - Index 0: Main data (RPM, gear, current iq/id)
 * - Index 1: Voltage data
 * - Index 4: Controller temperature
 * - Index 13: Motor temperature and throttle
 * 
 * The emulator provides realistic ebike simulation with dynamic
 * acceleration/deceleration patterns and proper data relationships.
 */

 #include <NimBLEDevice.h>
 #include <math.h>
 
 // Configuration constants
 #define DEVICE_NAME "FarDriver_Emu"
 #define LED_PIN 2
 #define LED_BLINK_INTERVAL 500
 #define PACKET_UPDATE_INTERVAL 20  // Reduced from 30ms to 20ms for faster updates
 #define PACKET_SIZE 16
 #define PACKET_HEADER 0xAA
 
 // Forward declarations
 void restart_ble_advertising();
 
 // Standard Nordic UART Service UUIDs
 #define NUS_SERVICE_UUID        "6E400001-B5A3-F393-E0A9-E50E24DCCA9E"
 #define NUS_TX_CHARACTERISTIC_UUID "6E400003-B5A3-F393-E0A9-E50E24DCCA9E"
 #define NUS_RX_CHARACTERISTIC_UUID "6E400002-B5A3-F393-E0A9-E50E24DCCA9E"
 
 // Custom FarDriver service (for EKSR Instrument compatibility)
 // Based on community findings and common FarDriver BLE implementations
 #define FARDIVER_SERVICE_UUID        "FFE0"
 #define FARDIVER_CHARACTERISTIC_UUID "FFEC"
 
 // Packet indices for different data types
 enum PacketIndex {
     INDEX_MAIN_DATA = 0,    // RPM, gear, current
     INDEX_VOLTAGE = 1,      // Voltage, power
     INDEX_CONTROLLER_TEMP = 4, // Controller temperature
     INDEX_MOTOR_THROTTLE = 13   // Motor temp, throttle
 };
 
 // Ebike simulation state
 struct EbikeState {
     float current_speed;      // Current speed in km/h
     float target_speed;       // Target speed for acceleration/deceleration
     float acceleration_rate;  // Acceleration rate in km/h per second
     float throttle_position;  // Throttle position (0.0 to 1.0)
     bool is_accelerating;     // Whether currently accelerating
     bool is_decelerating;     // Whether currently decelerating
     unsigned long last_update; // Last update timestamp
     int cycle_count;          // Cycle counter for pattern changes
 };
 
 // Global variables
 NimBLECharacteristic* pFarDriverCharacteristic = nullptr;
 NimBLECharacteristic* pNusTxCharacteristic = nullptr;
 NimBLECharacteristic* pNusRxCharacteristic = nullptr;
 bool deviceConnected = false;
 unsigned long lastBlinkTime = 0;
 bool ledState = false;
 
 // Ebike simulation state
 EbikeState ebike_state = {
     .current_speed = 0.0f,
     .target_speed = 0.0f,
     .acceleration_rate = 2.0f,  // 2 km/h per second
     .throttle_position = 0.0f,
     .is_accelerating = false,
     .is_decelerating = false,
     .last_update = 0,
     .cycle_count = 0
 };
 
 // Packet indices array - matches firmware expectations exactly
 static const uint8_t PACKET_INDICES[] = {0, 1, 4, 13};  // Firmware expects these exact indices
 static const size_t NUM_PACKET_INDICES = sizeof(PACKET_INDICES) / sizeof(PACKET_INDICES[0]);
 
 // Server callbacks class
 class ServerCallbacks : public NimBLEServerCallbacks {
     void onConnect(NimBLEServer* pServer, ble_gap_conn_desc* desc) {
         Serial.println("[Emulator] onConnect callback triggered");
         deviceConnected = true;
         // Don't set LED here - let the loop() handle it
         Serial.println("[Emulator] Device connected");
         Serial.printf("[Emulator] Client: %02X:%02X:%02X:%02X:%02X:%02X\n", 
             desc->peer_ota_addr.val[5], desc->peer_ota_addr.val[4], desc->peer_ota_addr.val[3],
             desc->peer_ota_addr.val[2], desc->peer_ota_addr.val[1], desc->peer_ota_addr.val[0]);
         Serial.printf("[Emulator] Connection handle: %d\n", desc->conn_handle);
     }
     
     void onDisconnect(NimBLEServer* pServer) {
         Serial.println("[Emulator] onDisconnect callback triggered");
         deviceConnected = false;
         // Don't set LED here - let the loop() handle it
         Serial.println("[Emulator] Device disconnected");
         
         // Restart advertising when client disconnects
         Serial.println("[Emulator] Client disconnected - restarting BLE advertising...");
         restart_ble_advertising();
     }
     
     void onMTUChange(uint16_t MTU, ble_gap_conn_desc* desc) {
         Serial.printf("[Emulator] MTU: %d\n", MTU);
     }
 };
 
 // Nordic UART Service callbacks
 class NusCallbacks : public NimBLECharacteristicCallbacks {
     void onWrite(NimBLECharacteristic* pCharacteristic) {
         std::string rxValue = pCharacteristic->getValue();
         if (!rxValue.empty()) {
             Serial.print("[Emulator] Received: ");
             Serial.println(rxValue.c_str());
         }
     }
 };
 
 // CRC-16/MODBUS calculation function
 // Polynomial: 0xA001 (reversed 0x8005)
 // Initial value: 0xFFFF
 // No XOR out
 // No reverse input/output bytes
 uint16_t crc16_modbus(const uint8_t *data, size_t len) {
     uint16_t crc = 0xFFFF;
     for (size_t i = 0; i < len; i++) {
         crc ^= (uint16_t)data[i];
         for (int j = 0; j < 8; j++) {
             if ((crc & 0x0001) != 0) {
                 crc = (crc >> 1) ^ 0xA001;
             } else {
                 crc = crc >> 1;
             }
         }
     }
     return crc;
 }
 
 // Update ebike simulation state
 void update_ebike_simulation() {
     unsigned long current_time = millis();
     float delta_time = (current_time - ebike_state.last_update) / 1000.0f; // Convert to seconds
     ebike_state.last_update = current_time;
     
     // Start accelerating immediately when connected, don't wait for cycle counter
     if (deviceConnected && ebike_state.current_speed < 0.1f) {
         // Start acceleration phase immediately
         ebike_state.target_speed = 25.0f; // Target 25 km/h
         ebike_state.is_accelerating = true;
         ebike_state.is_decelerating = false;
         ebike_state.acceleration_rate = 2.0f; // 2 km/h per second
         ebike_state.cycle_count = 0; // Reset cycle counter
     }
     
     // Update cycle counter every 10 seconds (only after initial acceleration)
     if (current_time % 10000 < 30 && ebike_state.current_speed > 5.0f) { // Within 30ms window
         ebike_state.cycle_count++;
         
         // Change behavior every 30 seconds (3 cycles of 10 seconds each)
         if (ebike_state.cycle_count % 3 == 0) {
             // Start acceleration phase
             ebike_state.target_speed = 25.0f; // Target 25 km/h
             ebike_state.is_accelerating = true;
             ebike_state.is_decelerating = false;
             ebike_state.acceleration_rate = 2.0f; // 2 km/h per second
         } else if (ebike_state.cycle_count % 3 == 1) {
             // Maintain speed phase
             ebike_state.is_accelerating = false;
             ebike_state.is_decelerating = false;
         } else {
             // Deceleration phase
             ebike_state.target_speed = 0.0f;
             ebike_state.is_accelerating = false;
             ebike_state.is_decelerating = true;
             ebike_state.acceleration_rate = 1.5f; // Slower deceleration
         }
     }
     
     // Update speed based on current state
     if (ebike_state.is_accelerating) {
         ebike_state.current_speed += ebike_state.acceleration_rate * delta_time;
         if (ebike_state.current_speed >= ebike_state.target_speed) {
             ebike_state.current_speed = ebike_state.target_speed;
             ebike_state.is_accelerating = false;
         }
         // Increase throttle during acceleration
         ebike_state.throttle_position = min(1.0f, ebike_state.throttle_position + 0.1f * delta_time);
     } else if (ebike_state.is_decelerating) {
         ebike_state.current_speed -= ebike_state.acceleration_rate * delta_time;
         if (ebike_state.current_speed <= ebike_state.target_speed) {
             ebike_state.current_speed = ebike_state.target_speed;
             ebike_state.is_decelerating = false;
         }
         // Decrease throttle during deceleration
         ebike_state.throttle_position = max(0.0f, ebike_state.throttle_position - 0.15f * delta_time);
     } else {
         // Maintain speed - slight throttle adjustments
         ebike_state.throttle_position = 0.3f + 0.1f * sin(current_time / 2000.0f);
     }
     
     // Ensure speed doesn't go negative
     if (ebike_state.current_speed < 0.0f) {
         ebike_state.current_speed = 0.0f;
     }
 }
 
 // Optimized packet generation with dynamic ebike simulation
 void fill_packet(uint8_t* data, uint8_t index, uint32_t timestamp) {
     // Update ebike simulation
     update_ebike_simulation();
     
     // Initialize packet header and clear all bytes
     data[0] = PACKET_HEADER;  // 0xAA header
     data[1] = index;          // Packet index
     
     // Clear remaining bytes (payload and checksum area)
     memset(&data[2], 0, PACKET_SIZE - 2);
     
     switch(index) {
         case 0: {  // Index 0: RPM, gear, current
             // Gear bits (mid position) - bits 2-3 of byte 2 (data[2])
             // Firmware expects: ((pData[2] >> 2) & 0x03) then subtracts 1
             // 00=high, 11=mid, 10=low, (00=Disabled)
             // For mid gear (2), we need 11 in bits 2-3, so 0x0C
             data[2] = 0x0C;  // 11 = mid gear (bits 2-3)
             
             // Calculate RPM based on speed (realistic ebike relationship)
             // Assuming 4:1 gear ratio and 1.35m wheel circumference
             float wheel_rpm = (ebike_state.current_speed * 1000.0f) / (60.0f * 1.35f); // Convert km/h to m/min, then to RPM
             uint16_t rpm = (uint16_t)(wheel_rpm * 4.0f); // Apply gear ratio
             
             // Add some realistic variation
             rpm += (uint16_t)(50 * sin(timestamp / 500.0f));
             
             // Ensure RPM stays in reasonable range
             if (rpm < 50) rpm = 50;  // Lower minimum to allow for low speeds
             if (rpm > 3000) rpm = 3000;
             
             // RPM at bytes 4-5 (firmware expects: ((uint16_t)pData[4] << 8) | pData[5])
             // This means data[4] is MSB, data[5] is LSB (Big-endian)
             data[4] = (rpm >> 8) & 0xFF;
             data[5] = rpm & 0xFF;
             
             // Debug output for speed and RPM
             if (index == 0) { // Only for main data packet
                 Serial.printf("[Emulator] Speed: %.1f km/h, RPM: %d, Throttle: %.1f%%\n", 
                     ebike_state.current_speed, rpm, ebike_state.throttle_position * 100.0f);
             }
             
             // Calculate current values based on throttle and speed
             float power_factor = ebike_state.throttle_position * (ebike_state.current_speed / 25.0f);
             int16_t iq = (int16_t)(300 + 400 * power_factor); // 3A to 7A range
             int16_t id = (int16_t)(100 + 200 * power_factor); // 1A to 3A range
             
             // Add some variation
             iq += (int16_t)(20 * sin(timestamp / 300.0f));
             id += (int16_t)(10 * sin(timestamp / 400.0f));
             
             // Current values at bytes 8-11 (firmware expects: pData[8-9] for iq, pData[10-11] for id)
             // This means data[8] is MSB, data[9] is LSB for iq (Big-endian)
             // This means data[10] is MSB, data[11] is LSB for id (Big-endian)
             data[8] = (iq >> 8) & 0xFF;
             data[9] = iq & 0xFF;
             data[10] = (id >> 8) & 0xFF;
             data[11] = id & 0xFF;
             break;
         }
         
         case 1: {  // Index 1: Voltage
             // Voltage with slight variation based on load
             float voltage_variation = 1.0f - (ebike_state.throttle_position * 0.05f); // 5% drop under load
             uint16_t voltage = (uint16_t)(900 * voltage_variation); // Base 90.0V in 100mV steps
             
             // Voltage at bytes 0-1 (firmware expects: ((uint16_t)pData[0] << 8) | pData[1])
             // This means data[2] is MSB, data[3] is LSB (Big-endian)
             data[2] = (voltage >> 8) & 0xFF;
             data[3] = voltage & 0xFF;
             break;
         }
         
         case 4: {  // Index 4: Controller temperature
             // Temperature increases with power usage
             uint8_t temp = (uint8_t)(35 + ebike_state.throttle_position * 15); // 35-50°C range
             
             // Temperature at byte 2 (firmware expects: (float)pData[2]) - corresponds to data[4]
             data[4] = temp; // Corrected: pData[2] maps to data[4]
             break;
         }
         
         case 13: {  // Index 13: Motor temp, throttle
             // Motor temperature follows controller temp with slight delay
             uint8_t motor_temp = (uint8_t)(40 + ebike_state.throttle_position * 20); // 40-60°C range
             
             // Motor temp at byte 0 (firmware expects: (float)pData[0]) - corresponds to data[2]
             data[2] = motor_temp;
             
             // Convert throttle position to raw ADC value (0-4095)
             uint16_t throttle_raw = (uint16_t)(ebike_state.throttle_position * 4095.0f);
             
             // Throttle at bytes 2-3 (firmware expects: ((uint16_t)pData[2] << 8) | pData[3]) - corresponds to data[4-5]
             // This means data[4] is MSB, data[5] is LSB (Big-endian)
             data[4] = (throttle_raw >> 8) & 0xFF;
             data[5] = throttle_raw & 0xFF;
             break;
         }
     }
     
     // --- CRC-16/MODBUS CHECKSUM CALCULATION ---
     // Calculate CRC-16 over the first 14 bytes (data[0] to data[13])
     uint16_t crc = crc16_modbus(data, 14);
 
     // Place the 2-byte CRC at the end of the packet (little-endian)
     data[14] = crc & 0xFF;          // Low byte
     data[15] = (crc >> 8) & 0xFF;   // High byte
 }
 
 // Print packet data in hex format
 void print_packet_debug(const uint8_t* data, uint8_t index) {
     Serial.printf("[Emulator] Packet %d: ", index);
     for (int i = 0; i < PACKET_SIZE; ++i) {
         Serial.printf("%02X ", data[i]);
     }
     Serial.println();
 }
 
 // Validate packet format matches FarDriver protocol (for debug/self-check)
 void validate_packet_format(const uint8_t* data, uint8_t index) {
     // Check header
     if (data[0] != PACKET_HEADER) {
         Serial.printf("[Emulator] ERROR: Invalid packet header: 0x%02X (expected 0x%02X)\n", data[0], PACKET_HEADER);
     }
     
     // Check index
     if (data[1] != index) {
         Serial.printf("[Emulator] ERROR: Packet index mismatch: %d (expected %d)\n", data[1], index);
     }
     
     // Check packet size
     if (PACKET_SIZE != 16) {
         Serial.printf("[Emulator] ERROR: Invalid packet size: %d (expected 16)\n", PACKET_SIZE);
     }
     
     // Validate CRC-16/MODBUS checksum
     uint16_t calculated_crc = crc16_modbus(data, 14); // Calculate CRC over first 14 bytes
     uint16_t received_crc = ((uint16_t)data[15] << 8) | data[14]; // Reconstruct received CRC (little-endian)
 
     if (received_crc != calculated_crc) {
         Serial.printf("[Emulator] ERROR: CRC mismatch: 0x%04X (calculated 0x%04X)\n", 
                      received_crc, calculated_crc);
     }
 }
 
 // Initialize BLE services
 void setup_ble_services(NimBLEServer* pServer) {
     // Create FarDriver service
     NimBLEService* pFarDriverService = pServer->createService(FARDIVER_SERVICE_UUID);
     pFarDriverCharacteristic = pFarDriverService->createCharacteristic(
         FARDIVER_CHARACTERISTIC_UUID,
         NIMBLE_PROPERTY::NOTIFY | NIMBLE_PROPERTY::WRITE
     );
     pFarDriverService->start();
     
     // Create Nordic UART Service (optional, remove if not needed by EKSR)
     NimBLEService* pNusService = pServer->createService(NUS_SERVICE_UUID);
     pNusTxCharacteristic = pNusService->createCharacteristic(
         NUS_TX_CHARACTERISTIC_UUID,
         NIMBLE_PROPERTY::NOTIFY
     );
     
     // Add descriptors for better compatibility
     pNusTxCharacteristic->createDescriptor("2901", NIMBLE_PROPERTY::READ, 20);
     pNusTxCharacteristic->createDescriptor("2902", NIMBLE_PROPERTY::READ | NIMBLE_PROPERTY::WRITE, 2);
     
     pNusRxCharacteristic = pNusService->createCharacteristic(
         NUS_RX_CHARACTERISTIC_UUID,
         NIMBLE_PROPERTY::WRITE | NIMBLE_PROPERTY::WRITE_NR
     );
     pNusRxCharacteristic->setCallbacks(new NusCallbacks());
     pNusService->start();
 }
 
 // Setup BLE advertising
 void setup_ble_advertising() {
     NimBLEAdvertising* pAdvertising = NimBLEDevice::getAdvertising();
     
     // Configure advertising data
     NimBLEAdvertisementData advData;
     advData.setName(DEVICE_NAME);
     advData.addServiceUUID(FARDIVER_SERVICE_UUID);
     pAdvertising->setAdvertisementData(advData);
     
     // Configure scan response
     NimBLEAdvertisementData scanResponseData;
     scanResponseData.setName(DEVICE_NAME);
     scanResponseData.addServiceUUID(NUS_SERVICE_UUID);
     pAdvertising->setScanResponseData(scanResponseData);
     
     // Set advertising parameters
     pAdvertising->setMinInterval(0x20); // 20ms
     pAdvertising->setMaxInterval(0x40); // 40ms
     
     pAdvertising->start();
 }
 
 // Restart BLE advertising with error checking
 void restart_ble_advertising() {
     NimBLEAdvertising* pAdvertising = NimBLEDevice::getAdvertising();
     
     if (pAdvertising) {
         // Stop advertising first if it's running
         if (pAdvertising->isAdvertising()) {
             pAdvertising->stop();
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
 void loop() {
     static size_t packetIndex = 0;
     static uint32_t timestamp = 0;
     static unsigned long lastConnectionCheck = 0;
     
     // Check connection status periodically
     unsigned long currentTime = millis();
     if (currentTime - lastConnectionCheck >= 1000) { // Check every second
         lastConnectionCheck = currentTime;
         
         // Get the server and check if there are any connected clients
         NimBLEServer* pServer = NimBLEDevice::getServer();
         if (pServer && pServer->getConnectedCount() > 0) {
             if (!deviceConnected) {
                 deviceConnected = true;
                 // digitalWrite(LED_PIN, HIGH); // Let the centralized logic handle the LED
                 Serial.println("[Emulator] Connection detected via server check");
                 Serial.printf("[Emulator] Connected clients: %d\n", pServer->getConnectedCount());
                 
                 // Send a test message immediately
                 if (pNusTxCharacteristic) {
                     const char* testMsg = "Hello from FarDriver Emulator!";
                     pNusTxCharacteristic->setValue((uint8_t*)testMsg, strlen(testMsg));
                     pNusTxCharacteristic->notify();
                     Serial.println("[Emulator] Sent initial test message");
                 }
             }
         } else {
             if (deviceConnected) {
                 deviceConnected = false;
                 // digitalWrite(LED_PIN, LOW); // Let the centralized logic handle the LED
                 Serial.println("[Emulator] Disconnection detected via server check");
             }
         }
         
         // Debug: Print connection status and simulation state every 5 seconds
         static unsigned long lastStatusPrint = 0;
         if (currentTime - lastStatusPrint >= 5000) {
             lastStatusPrint = currentTime;
             Serial.printf("[Emulator] Status - deviceConnected: %s, Server clients: %d\n", 
                 deviceConnected ? "true" : "false", 
                 pServer ? pServer->getConnectedCount() : 0);
             
             // Print ebike simulation state
             Serial.printf("[Emulator] Ebike State - Speed: %.1f km/h, Throttle: %.1f%%, Cycle: %d\n",
                 ebike_state.current_speed,
                 ebike_state.throttle_position * 100.0f,
                 ebike_state.cycle_count);
         }
     }
     
     // Handle LED state based on connection status
     if (!deviceConnected) {
         // Ensure advertising is running when not connected
         if (!NimBLEDevice::getAdvertising()->isAdvertising()) {
             Serial.println("[Emulator] Advertising stopped - restarting...");
             restart_ble_advertising();
         }
         
         // Blink LED when not connected
         if (currentTime - lastBlinkTime >= LED_BLINK_INTERVAL) {
             ledState = !ledState;
             digitalWrite(LED_PIN, ledState);
             lastBlinkTime = currentTime;
         }
         delay(100);
         return;
     } else {
         // When connected, ensure LED stays solid ON
         digitalWrite(LED_PIN, HIGH);
         // Reset blink state for next disconnection
         ledState = false;
     }
     
     // Send data packets when connected
     uint8_t data[PACKET_SIZE];
     fill_packet(data, PACKET_INDICES[packetIndex], timestamp);
     
     // Send to both services
     if (pFarDriverCharacteristic) {
         pFarDriverCharacteristic->setValue(data, PACKET_SIZE);
         pFarDriverCharacteristic->notify();
     }
     
     if (pNusTxCharacteristic) {
         pNusTxCharacteristic->setValue(data, PACKET_SIZE);
         pNusTxCharacteristic->notify();
     }
     
     // Debug output (can be disabled for production)
     print_packet_debug(data, PACKET_INDICES[packetIndex]);
     
     // Validate packet format (can be disabled for production)
     validate_packet_format(data, PACKET_INDICES[packetIndex]);
     
     // Update counters
     packetIndex = (packetIndex + 1) % NUM_PACKET_INDICES;
     timestamp += PACKET_UPDATE_INTERVAL;
     
     delay(PACKET_UPDATE_INTERVAL);
 } 

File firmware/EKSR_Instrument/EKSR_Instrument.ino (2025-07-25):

/*
  Code for the EKSR Instrument.
  Communicates with the FarDriver ND96530 Controller via Bluetooth BLE
  Displays data on a 240x320 pixel TFT display.

  Jesper Hansen, June 2022
  Various updates, October 2024

  Project home: https://github.com/magicmicros/EKSR_Instrument
  
*/
#define USE_NIMBLE 1

// uncomment this to include functions for message debugging on screen
//#define ON_SCREEN_MSG_DEBUG 1


#if USE_NIMBLE
#include "nimble.h"
#endif


#include <Preferences.h>
Preferences preferences;

#include "Free_Fonts.h"      // Include the header file attached to this sketch
#include "NotoSansBold36.h"  // Font attached to this sketch
#define AA_FONT_LARGE NotoSansBold36


// Analog touch input
#include <ATouch.h>
ATouch AT;

// TFT class and vars
#include <TFT_eSPI.h>                  // Master copy here: https://github.com/Bodmer/TFT_eSPI
TFT_eSPI tft = TFT_eSPI();             // Invoke library, pins defined in User_Setup_Select.h
TFT_eSprite spr = TFT_eSprite(&tft);   // Sprite for meter reading
TFT_eSprite vspr = TFT_eSprite(&tft);  // Sprite for voltage

uint16_t spr_width = 0;
uint16_t vspr_width = 0;

typedef enum {
  AS_CONNECTING,
  AS_MAIN,
  AS_ODOMETER,
  AS_SETTINGS,
} active_screen_e;

active_screen_e active_screen = AS_MAIN;  // Screen currently being displayed


class controller_data {
public:
  volatile uint16_t throttle;
  volatile uint8_t gear;
  volatile uint16_t rpm;
  volatile float controller_temp;
  volatile float motor_temp;
  volatile float speed;
  volatile float power;
  volatile float voltage;
};

controller_data ctr_data;


volatile float backlight = 50;


// Limits for battery stack display and power bar
float low_batt_limit = 86;
float high_batt_limit = 96;
float max_power = 20;

//
// wheel circumference
// adapt this to fit your bike
//
float wheel_circumference = 1.350;  // actual circumference, non-loaded is 1520mm

#if ON_SCREEN_MSG_DEBUG
// storage for incoming messages
uint8_t message_store[30][12];
#endif


// states for connection status ISM
typedef enum {
  CS_SEARCHING,
  CS_CONNECTED,
  CS_DISCONNECTED,
} connection_state_e;
connection_state_e connection_state = CS_SEARCHING;






/*********************************************************/

void ui_switch(void) {
  switch (active_screen) {
    case AS_CONNECTING:
      break;
    case AS_MAIN:
      active_screen = AS_ODOMETER;
      odometer_screen_init();
      break;
    case AS_ODOMETER:
      active_screen = AS_SETTINGS;
      settings_screen_init();
      break;
    case AS_SETTINGS:
      active_screen = AS_MAIN;
      main_screen_init();
      break;
  }
}


void ui_update(void) {
  switch (active_screen) {
    case AS_CONNECTING:
      break;
    case AS_MAIN:
      main_screen_update();
      break;
    case AS_ODOMETER:
      odometer_screen_update();
      break;
    case AS_SETTINGS:
      settings_screen_update();
      break;
  }
}



/*********************************************************/

//
// Touch Field Class
//
class Field {
public:
  Field(int x, int y, int w, int h) {
    _x = x;
    _y = y;
    _w = w;
    _h = h;
  }
  bool hit();
protected:
  int _x, _y, _w, _h;
};


bool Field::hit() {
  uint16_t x, y;
  if ((AT.getTouch(&x, &y)) > 0) {
    printf("touch at %d,%d\r\n", x, y);

    if ((x > _x) && (x < (_x + _w)) && (y > _y) && (y < (_y + _h))) {
      printf("field hit at %d,%d\r\n", x, y);
      return true;
    }
  }
  return false;
}

/*********************************************************/

//
// Button Class
//
class Button : public Field {
public:
  Button(int x, int y, int w, int h, const char *txt, const GFXfont *font = FSS12);
  void draw();
private:
  String _text;
  const GFXfont *_font;
};

Button::Button(int x, int y, int w, int h, const char *txt, const GFXfont *font)
  : Field(x, y, w, h) {
  _text = String(txt);
  _font = font;
}

void Button::draw() {

  tft.setTextColor(TFT_WHITE, TFT_BLACK);
  tft.setTextDatum(MC_DATUM);
  tft.setFreeFont(_font);
  tft.drawString(_text.c_str(), _x + _w / 2, _y + _h / 2);
  tft.drawRect(_x, _y, _w, _h, TFT_WHITE);
}

/*********************************************************/



//
// general touch fields
//
Field fNext(0, 0, 240, 40);

//
// odometer touch fields
//
Button bTotal(0, 280, 80, 40, "Total");
Button bTrip1(80, 280, 80, 40, "Trip1");
Button bTrip2(160, 280, 80, 40, "Trip2");
Button bReset(70, 200, 100, 40, "Reset");





/*****************************************************************************************************/
/*****************************************************************************************************/
/*****************************************************************************************************/

/*
    Total km , speed, power
    Trip 1 km , speed, power
    Trip 2 , speed, power

    km per kW
    
    Later, can perhaps add estimated range?  
 */

//
// Odometer Class
//
class Odometer {
public:
  Odometer(const char *label, bool can_reset = false);
  void update_distance(float distance);
  void update_speed(float speed);
  void update_power(float power);
  void draw();
  void load();
  void save();
  void reset();
  //private:
  String _label;

  bool _can_reset;
  float _distance;
  float _speed;
  float _power;
  float _last_distance;
  float _last_speed;
  float _last_power;
};

Odometer::Odometer(const char *label, bool can_reset) {
  _label = String(label);
  _can_reset = can_reset;
  load();
}

void Odometer::update_distance(float distance) {
  _distance += distance;
}

void Odometer::update_speed(float speed) {
  if (speed > _speed)
    _speed = speed;
}

void Odometer::update_power(float power) {
  if (power > _power)
    _power = power;
}

void Odometer::draw() {
  bool isTotal = false;
  if (!_can_reset)  // sneaky way to determine if this is the Total page
    isTotal = true;

  tft.setTextDatum(TC_DATUM);
  tft.drawString(_label, 120, 40);

  tft.setTextDatum(TL_DATUM);
  tft.drawString("Distance", 0, 80);
  tft.drawString("Speed", 0, 120);
  tft.drawString("Power", 0, 160);

  if (isTotal)
    tft.drawString("km/kW", 0, 200);


  tft.setTextDatum(TR_DATUM);
  tft.drawFloat(_distance, 1, 195, 80);
  tft.drawFloat(_speed, 1, 195, 120);
  tft.drawFloat(_power, 1, 195, 160);
  if (isTotal) {
    float kmkw = 0;

    // need power consumtion for this
    tft.drawFloat(kmkw, 1, 195, 200);
  }

  tft.setFreeFont(FSS9);
  tft.setTextDatum(TL_DATUM);
  tft.setTextPadding(tft.textWidth("77"));
  tft.drawString("km", 200, 83);
  tft.setTextPadding(tft.textWidth("777"));
  tft.drawString("km/h", 200, 123);
  tft.setTextPadding(tft.textWidth("77"));
  tft.drawString("kW", 200, 163);


  // draw buttons
  bTotal.draw();
  bTrip1.draw();
  bTrip2.draw();

  if (_can_reset)   // sneaky way to determine if this isn't the Total page
    bReset.draw();  // only draw reset button on trip pages
}
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

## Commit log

2025-07-24 Add ESP32-S3 BLE multi-role support section to README, detailing capabilities and use cases
2025-07-24 Refactor LED handling in FarDriverEmulator.ino to centralize control logic, ensuring LED state is managed in the loop() function rather than in connection callbacks.
2025-07-24 Update README to note issue with client connection and LED status in BLE emulator
2025-07-24 run auto formatter on arduino ide
2025-07-25 Refactor BLE advertising logic in FarDriverEmulator.ino to ensure reliable reconnection. Reduced packet update interval for faster data transmission. Added error handling for BLE advertising restart 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
    [FarDriverEmulator.ino]
2025-07-25 Add connection controls to EKSRDisplayEnhanced for improved user interaction
    Implemented connection and disconnection buttons in the sidebar, enhancing user control over BLE device connections. Added functionality to update button states based on connection status, ensuring a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
2025-07-25 Revamp color scheme and button styles in PC display for enhanced accessibility and modern design
    Updated the color palette to align with a modern 2024 design system, improving contrast and accessibility. Refactored button configurations to utilize new color mappings, ensuring a consistent user i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
2025-07-25 Implement terminal message filtering and add custom checkbox for enhanced user control
    Introduced a filtering system for terminal messages, allowing users to selectively display log messages based on their severity. Added a new ModernCheckbox class for improved checkbox styling and hov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
2025-07-28 Add BLE device management features to EKSRDisplayEnhanced
    Introduced a new section for displaying and managing BLE devices within the EKSRDisplayEnhanced interface. This includes a device list with refresh functionality, improved connection handling for bot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
2025-09-04 Enhance EKSR Instrument Emulator Suite with new Hall Motor Emulator and improved FarDriver BLE Emulator
    Added a new Hall Motor Emulator for simulating BLDC motor Hall sensor signals, enabling bench testing of motor controllers without physical motors. Updated the FarDriver BLE Emulator to include CRC-16/MODBUS checksum for improved error detection and enhanced packet validation. Revised README documentation to reflect new features and usage instructions for both emulators, ensuring clarity for developers and users. This update aims to streamline testing processes and improve overall emulator functionality.
    [FarDriverEmulator.ino, HallMotorEmulator.ino]
2025-09-04 Refactor EKSRDisplayEnhanced to improve BLE device management and connection handling
    Updated the EKSRDisplayEnhanced interface to enhance BLE device management features, including a more responsive device list and improved connection handling for FarDriver and YuanQu devices. This up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
2025-09-04 Remove ESP32 Fardriver BLE Controller code and associated README documentation
    Deleted the ESP32_Fardriver_BLE_Controller.ino file and its README.md to streamline the project by removing unused components. This cleanup enhances maintainability and focuses the codebase on active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
